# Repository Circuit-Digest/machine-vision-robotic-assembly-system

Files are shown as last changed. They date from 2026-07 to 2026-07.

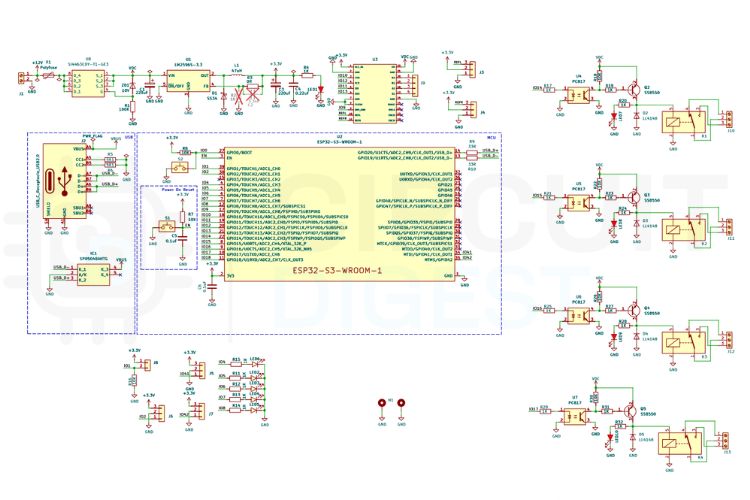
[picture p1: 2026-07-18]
Images/schematics_Controller.jpg

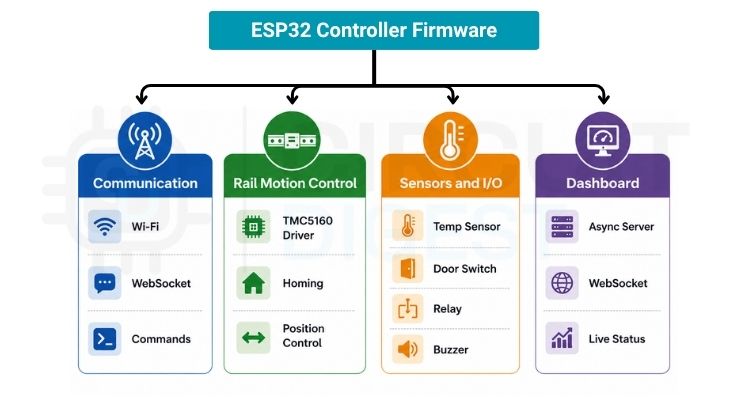
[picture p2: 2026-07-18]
Images/Software-Architecture.jpg

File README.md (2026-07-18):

<div align="center">

# 🤖 Machine Vision-Based Robotic Assembly System Using MechArm 270 and Jetson Nano

**A real-time computer-vision system that drives a 6-DOF robotic arm + linear rail to autonomously assemble two toy cars, verifying every part placement using black-pixel ROI detection on an on-board webcam.**







<br><br>
Robotic Assembly Line Vision Demo

</div>

---

## 📖 Table of Contents

1. [Project Overview](#-project-overview)
2. [Key Features](#-key-features)
3. [System Architecture](#-system-architecture)
4. [Hardware Requirements](#-hardware-requirements)
5. [Software Requirements & Installation](#-software-requirements--installation)
6. [Configuration](#-configuration)
7. [Running the Server](#-running-the-server)
8. [Dashboard Guide](#-dashboard-guide)
9. [Calibration Workflow](#-calibration-workflow)
10. [Vision Pipeline](#-vision-pipeline)
11. [Inspection Stations](#-inspection-stations)
12. [Waypoint System](#-waypoint-system)
13. [Socket.IO Event Reference](#-socketio-event-reference)
14. [Project Structure](#-project-structure)
15. [Troubleshooting](#-troubleshooting)
16. [Contributing](#-contributing)
17. [License](#-license)

---

## 🎯 Project Overview

This system orchestrates a **MechArm 270** 6-DOF robotic arm mounted on a **stepper-driven linear rail** to perform automated, vision-verified pick-and-place assembly of two toy cars.

The arm visits five physical stations. At each inspection station it positions its **wrist-mounted webcam** over a part tray, and a real-time OpenCV pipeline **verifies the correct component is present** using black-pixel ROI analysis before the arm is allowed to pick it up. A missing part immediately halts the sequence, triggers a **physical buzzer alert**, and waits for an operator to place the correct component.

The entire stack — robot control, vision processing, rail control, and web dashboards — runs as a **single Python process on port 5000**, eliminating all inter-service network latency.

---

## ✨ Key Features

| Feature | Description |
|---|---|
| 🎥 **Live MJPEG Stream** | Real-time webcam feed with annotated ROI overlays served to the browser |
| 🔍 **Black-Pixel ROI Detection** | Station-aware part detection using calibrated bounding boxes and HSV black masking |
| 🤖 **Wi-Fi Arm Control** | Non-blocking TCP socket control of MechArm 270 via `pymycobot` |
| 🚂 **ESP32 Rail Control** | HTTP-driven stepper linear rail with 5 presets (P1–P5) |
| 🚦 **Physical Indicators** | Green/Red LED + buzzer relay control for workshop-audible alerts |
| ✅ **Assembly Checklist** | Live progress bar and per-part checklist updating on every verification |
| 🖥️ **Three Dashboards** | Home display, Operator dashboard, Waypoint editor — all browser-based |
| 🛡️ **Sim Mode Fallback** | Full simulation when no hardware is connected — no code changes needed |
| 💾 **JSON Persistence** | All waypoints, poses, ROIs, and network config survive server restarts |

---

## 🏗️ System Architecture

```
┌─────────────────────────────────────────────────────────────────┐
│            main.py  (single process, port 5000)       │
│                                                                  │
│  ┌──────────────┐   ┌──────────────┐   ┌─────────────────────┐ │
│  │ RobotManager │   │  RailManager │   │  RailIndicatorMgr   │ │
│  │  Wi-Fi TCP   │   │  HTTP / ESP32│   │  HTTP relay control  │ │
│  └──────┬───────┘   └──────┬───────┘   └──────────┬──────────┘ │
│         │                  │                        │            │
│  ┌──────▼──────────────────▼───────────────────────▼──────────┐ │
│  │                   PlaybackEngine                            │ │
│  │  Sequences arm + rail movements + vision verification       │ │
│  └──────────────────────────┬──────────────────────────────────┘ │
│                             │  shared in-process memory           │
│  ┌──────────────────────────▼──────────────────────────────────┐ │
│  │             vision_thread()  (~30 FPS)                      │ │
│  │   OpenCV: Black-pixel ROI detection per station             │ │
│  └─────────────────────────────────────────────────────────────┘ │
│                                                                  │
│  Flask Routes + Socket.IO  →  Browser Dashboards                │
└─────────────────────────────────────────────────────────────────┘
```

### Data Flow

```
Camera → vision_thread → stable_detected_parts (dict)
                              ↓ (zero-latency in-process read)
                         PlaybackEngine → verifies part → continues sequence
                              ↓
                         Socket.IO → Browser (checklist, log, progress)
```

---

## 🔧 Hardware Requirements

| Component | Specification | Notes |
|---|---|---|
| **Robot Arm** | Elephant Robotics MechArm 270 | Wi-Fi model required |
| **Linear Rail** | Custom stepper rail with ESP32-C6 | 5 presets: P1–P5 |
| **Camera** | USB webcam (640×480 minimum) | Wrist-mounted on arm |
| **Relay Board** | 3-channel relay (12V) | Buzzer + Green/Red LED |
| **Network** | Wi-Fi AP or router | Arm, ESP32, and host PC on same LAN |
| **Host Computer** | Any x86/ARM Linux or Windows PC | Python 3.9+ required |

> [!NOTE]
> The system runs in full **simulation mode** if no hardware is connected. The camera stream is replaced by an animated mock feed, all Socket.IO events fire normally, and you can test the complete UI and checklist flow without any physical hardware.

---

## 💻 Software Requirements & Installation

### 1. Clone the repository

```bash
git clone https://github.com/YOUR_USERNAME/machine-vision-robotic-assembly-system.git
cd machine-vision-robotic-assembly-system
```

### 2. Create a virtual environment (recommended)

```bash
python -m venv venv

# Windows
venv\Scripts\activate

# Linux / macOS
source venv/bin/activate
```

### 3. Install dependencies

```bash
pip install -r requirements.txt
```

### Dependency Overview

| Package | Purpose |
|---|---|
| `flask` | Web server & template rendering |
| `flask-socketio` | Real-time WebSocket transport |
| `requests` | HTTP calls to the ESP32 Rail API |
| `pymycobot` | MechArm 270 Wi-Fi TCP SDK |
| `opencv-python` | Video capture, black-pixel ROI masking, MJPEG stream |
| `numpy` | Array operations for vision pipeline |

---

## ⚙️ Configuration

### Step 1 — Set your network IPs

Edit **`config.py`** and update the two IP constants at the bottom of the file:

```python
ARM_IP         = "192.168.1.100"   # Your MechArm270's Wi-Fi IP address
RAIL_IP        = "192.168.1.101"   # Your ESP32-C6 Rail controller IP
```

> [!TIP]
> You can also set these at runtime **without restarting the server** — open the Operator Dashboard, click the gear icon ⚙️, and enter your IPs. They are saved to `robot_config.json` and `rail_config.json` and take effect immediately.

### Step 2 — Camera index

In `config.py`, set the correct USB camera index:

```python
CAMERA_INDEX = 0    # 0 = default (first USB camera)
                    # 1 = second USB camera, etc.
```

### Step 3 — Vision detection thresholds

Tune these in `config.py` to match your lighting and part colours:

```python
# Black part detection
BLACK_HSV_LOWER = (0,   0,   0)    # HSV lower bound for black
BLACK_HSV_UPPER = (180, 255, 50)   # V < 50 = genuinely dark/black
BLACK_PIXEL_RATIO = 0.10           # 10% of ROI must be black to count as "present"

# Temporal hysteresis (noise suppression)
CONFIRM_FRAMES   = 5    # frames a part must be seen before "stable"
DISAPPEAR_FRAMES = 10   # frames a part must be missing before "lost"
```

### Step 4 — Runtime-persisted configuration files

The following JSON files are auto-generated and updated by the dashboards. They override the `config.py` defaults:

| File | Contents | Editable via |
|---|---|---|
| `robot_config.json` | Arm IP, port, axis calibration offsets | Operator Dashboard ⚙️ |
| `rail_config.json` | Rail ESP32 IP | Operator Dashboard ⚙️ |
| `camera_settings.json` | Brightness, contrast, exposure, gain | Operator Dashboard 🎥 |
| `scan_poses.json` | 6-joint arm angles per inspection station | Waypoint Editor → Scan Poses |
| `roi_boundaries.json` | Per-part pixel bounding boxes (ROI) | Operator Dashboard → ROI Editor |
| `zone_boundaries.json` | Spatial zone definitions per station | Operator Dashboard → Zone Editor |
| `waypoints.json` | Full arm + rail motion sequence | Waypoint Editor |

> [!WARNING]
> The `waypoints.json` included in this repository was recorded on a **specific physical rig**. Joint angles and positions will **not transfer** to a different robot or table layout. You must re-record all waypoints using the Waypoint Editor for your own setup.

---

## 🚀 Running the Server

```bash
python main.py
```

The server starts on `http://0.0.0.0:5000`. Open a browser and navigate to:

| URL | Dashboard |
|---|---|
| `http://localhost:5000/` | 🏠 Home Display Dashboard |
| `http://localhost:5000/camera_view` | 🖥️ Operator Dashboard |
| `http://localhost:5000/editor` | ✏️ Waypoint Editor |

On startup you will see:

```
======================================================================
  Robotic Assembly System (MechArm 270 & Jetson Nano) -> http://localhost:5000
  Robotic Arm + Stepper Linear Rail + Black-pixel ROI Vision Integrated.
======================================================================
```

The robot arm and rail connections are made in the background — if they fail the server continues in simulation mode and retries every 15 seconds.

---

## 🖥️ Dashboard Guide

### 🏠 Home Display Dashboard (`/`)

Clean status overview, suitable for display on a monitor during operation.

```
┌──────────────────────────┬──────────────────────┐
│   Live Camera Stream     │   System Info         │
│   (annotated MJPEG)      │   Robot: MechArm 270  │
│                          │   Detection: Black ROI│
├──────────────────────────┼──────────────────────┤
│   Last Detection         │  Assembly Progress   │
│   Snapshot               │  ████████░░░  75%    │
│                          │                      │
│                          │  ✅ Chassis 1         │
│                          │  ✅ Chassis 2         │
│                          │  ✅ WheelBase 1a      │
│                          │  ⏳ WheelBase 2a      │
│                          │  ...                  │
│                          │                      │
│                          │  Sensor: 24.3°C      │
│                          │  Door: CLOSED        │
│                          │                      │
│                          │  System Log          │
│                          │  ✓ Chassis 1 confirmed│
└──────────────────────────┴──────────────────────┘
```

- **▶ Play Sequence** — starts the full automated assembly run
- **⏹ Stop Arm** — emergency halt

### 🖥️ Operator Dashboard (`/camera_view`)

Full-featured operator view for monitoring and controlling the assembly:

- **Live annotated stream** — ROI boxes (grey → yellow → green), part labels, pixel-ratio readout, station overlay
- **Robot telemetry** — 6 joint angles, XYZ coordinates updated every 200 ms
- **Assembly checklist** — all parts for both cars, updating in real time
- **8-Switch Simulator Panel** — toggle any part as "present" for dry-run testing without physical components
- **Halt/Error Panel** — if the sequence stops on a missing part, this panel shows the reason and a restart button

### ✏️ Waypoint Editor (`/editor`)

Engineering tool for teaching the robot its motion sequence:

1. **Jog controls** — move each of the 6 joints or X/Y/Z coordinates from the browser
2. **Record** — save the current arm pose as a new waypoint (angles, coords, or both)
3. **Edit sequence** — rename, reorder, adjust speed, vacuum action, delay, and rail preset per waypoint
4. **Scan Pose console** — jog the arm to the perfect camera inspection angle, then click **Set P1** (or P2/P4/P5) to save to `scan_poses.json`
5. **Motor calibration** — lock/unlock individual joints, adjust motor power levels
6. **Network settings** — change Arm IP, Rail IP, and speed without restarting the server

---

## 📐 Calibration Workflow

Follow this sequence when setting up on a new physical rig:

```
1. Physical setup
   └─ Mount arm on rail, position part trays at stations P1, P2, P4, P5

2. Network configuration
   └─ Set ARM_IP and RAIL_IP in config.py or via Operator Dashboard ⚙️

3. Camera verification
   └─ Open /camera_view, check live stream
   └─ Adjust CAMERA_INDEX in config.py if wrong camera opens

4. Scan pose recording  (Waypoint Editor → 📸 Inspection Scan Poses)
   └─ Jog arm to view P1 tray → click "Set P1 (Chassis)"
   └─ Repeat for P2, P4, P5

5. ROI calibration  (Operator Dashboard → ROI Editor)
   └─ Move arm to scan pose for each station
   └─ Draw bounding boxes around each part slot on the video frame
   └─ Save → updates roi_boundaries.json

6. Detection threshold tuning  (config.py)
   └─ Adjust BLACK_PIXEL_RATIO until parts detect cleanly
   └─ Use 8-Switch Simulator to verify checklist behaviour

7. Waypoint recording  (Waypoint Editor)
   └─ Record pick positions at each station
   └─ Record place positions at P3 (assembly zone)
   └─ Add vision_check waypoints before each pick
   └─ Test with "Skip Vision" mode first, then enable vision checks

8. Full test run
   └─ Place parts at all stations
   └─ Click ▶ Play Sequence on Home Dashboard
   └─ Verify checklist completes 100%
```

---

## 👁️ Vision Pipeline

The vision system runs in a **dedicated background thread** at ~30 FPS using OpenCV.

### Black-Pixel ROI Detection

The only detection method used is black-pixel ratio analysis within calibrated Region of Interest (ROI) bounding boxes:

```
Frame (BGR)
  │
  ├─ GaussianBlur (5×5) → HSV conversion
  │
  └─ For each active part at current station:
        Crop frame to ROI bounding box  (from roi_boundaries.json)
        Apply black HSV mask: H[0-180] S[0-255] V[0-50]
        ratio = countNonZero(mask) / roi_area
        present = ratio - ambient_baseline ≥ BLACK_PIXEL_RATIO (10%)
```

An **adaptive ambient baseline** is captured on the first frame after the arm settles at its scan pose. This compensates automatically for dim environments or dark surfaces in the background.

### How Detection Works Per Station

1. Rail moves arm to station (e.g. P1)
2. Arm commands itself to pre-saved scan pose for that station (`scan_poses.json`)
3. Vision thread activates and begins checking only the parts registered to that station (`STATION_PARTS` in `config.py`)
4. For each active part slot, it crops the frame to the ROI (`roi_boundaries.json`) and measures the black-pixel ratio
5. Parts meeting the threshold are accumulated over frames; confirmed after `CONFIRM_FRAMES` consecutive detections

### Hysteresis Filtering

Raw frame results are not immediately acted upon — a two-stage filter prevents false positives from motion blur, shadows, or lighting glitches:

```
MISSING ──[seen for 5 consecutive frames]──→ STABLE (detected)
STABLE  ──[missing for 10 consecutive frames]──→ MISSING
```

### Stream Annotation

During an active vision check, the live stream shows:

- **Grey boxes** — ROI is active, part not detected
- **Yellow boxes** — part seen but not yet stable (accumulating frames)
- **Green boxes** — part confirmed stable (checkmark ✓ + ratio %)
- **Station panel** — current station label + list of active part slots

---

## 🏭 Inspection Stations

| Station | Preset | Detection Method | Parts Verified |
|---|---|---|---|
| **P1** | `P1 (Chassis)` | Black-pixel ROI | Chassis 1, Chassis 2 |
| **P2** | `P2 (Wheelbase)` | Black-pixel ROI | WheelBase 1a, 2a, 1b, 2b |
| **P3** | `P3 (Assemble)` | *(none — assembly zone)* | — |
| **P4** | `P4 (Wheels)` | Black-pixel ROI (8 slots) | Wheel Slots 1–8 |
| **P5** | `P5 (Body)` | Black-pixel ROI | Body 1, Body 2 |

---

## 📋 Waypoint System

### Waypoint Record Format

```json
{
  "name": "Pick Chassis 1",
  "type": "angles",
  "data": [15.2, -45.1, 90.0, 0.0, 45.0, 0.0],
  "speed": 40,
  "vacuum": "on",
  "vacuum_delay_ms": 300,
  "delay_ms": 200,
  "rail_preset": "P1"
}
```

| Field | Values | Description |
|---|---|---|
| `type` | `angles`, `coords`, `both`, `vision_check` | Movement type |
| `data` | `[j1, j2, j3, j4, j5, j6]` or `[x, y, z, rx, ry, rz]` | Target position |
| `vacuum` | `"on"`, `"off"`, `"none"` | Vacuum pump action after movement |
| `rail_preset` | `"P1"`–`"P5"`, `"NONE"` | Rail position to move to after arm arrives |
| `speed` | `1`–`100` | Arm movement speed percentage |

### `vision_check` Waypoint

A special waypoint type that **does not move the arm or rail**. It triggers a vision verification cycle:

```json
{
  "name": "Verify Chassis 1",
  "type": "vision_check",
  "rail_preset": "P1",
  "check_part": "Chassis 1"
}
```

When the PlaybackEngine reaches this waypoint it:
1. Commands the arm to the pre-saved scan pose for that station
2. Waits 1.5 s for mechanical settling
3. Activates vision detection for the named part
4. Waits until the part is stably detected (or halts on timeout/stop)
5. Emits `part_verified` to update the UI checklist

---

## 📡 Socket.IO Event Reference

### Server → Client

| Event | Key Payload Fields | Description |
|---|---|---|
| `robot_status` | `angles[]`, `coords[]`, `rail{}`, `vision_detected[]` | Full telemetry broadcast (every 200 ms) |
| `status` | `state`, `step`, `total`, `message` | Playback state machine update |
| `playback_progress` | `index`, `total`, `name`, `state` | Per-waypoint progress update |
| `part_verified` | `part`, `rail`, `snapshot_ts` | Part confirmed — update checklist |
| `vision_log` | `level`, `message` | Colour-coded log line for consoles |
| `detection_started` | `part`, `station` | Vision scan is active |
| `detection_stopped` | `part`, `station`, `found` | Vision scan ended |
| `snapshot_updated` | *(none)* | Last-detection image on disk has changed |
| `error` | `part`, `position`, `message` | Emergency stop / verification fault |
| `command_complete` | `action`, `cmd_id` | Arm command acknowledged by hardware |

### Client → Server

| Event | Payload | Description |
|---|---|---|
| `play_sequence` | `start_index`, `speed`, `skip_vision` | Start playback |
| `stop_sequence` | *(none)* | Emergency stop |
| `toggle_mock` | `part`, `value` | Toggle hardware simulator switch |
| `jog_joint` | `joint`, `delta`, `speed` | Move one joint by delta degrees |
| `jog_coord` | `axis`, `delta`, `speed` | Move in Cartesian space |
| `record_waypoint` | `type`, `name`, `vacuum`, `rail_preset`, `speed` | Save current pose |
| `set_scan_pose` | `station` | Save current arm angles as scan pose |
| `update_ip` | `arm_ip`, `rail_ip` | Change network config without restart |

---

## 📁 Project Structure

```
machine-vision-robotic-assembly-system/
│
├── main.py                    # Main Flask + SocketIO application (2,700+ lines)
├── config.py                  # Shared constants: IPs, HSV thresholds, station maps
├── requirements.txt           # Python dependencies
├── .gitignore                 # Excludes __pycache__, logs, runtime snapshots
├── LICENSE                    # MIT License
│
├── templates/
│   ├── home.html              # 🏠 Home display (live feed + status checklist)
│   ├── operator_view.html     # 🖥️  Operator Dashboard (full telemetry + controls)
│   └── waypoint_editor.html   # ✏️  Waypoint Editor & Scan Pose console
│
├── static/
│   └── socket.io.min.js       # Socket.IO client (served locally, no CDN dependency)
│
├── hardware/                  # 🔌 PCB & Schematic Design Files
│   ├── schematic.pdf          # PCB schematic diagram (PDF)
│   ├── gerbers.zip            # Manufacturing-ready Gerber files
│   ├── controller.kicad_sch   # KiCad Schematic design
│   ├── controller.kicad_pcb   # KiCad PCB board layout
│   ├── controller.kicad_pro   # KiCad Project file
│   └── controller.kicad_prl   # KiCad Project local settings
│
├── Images/                    # 🖼️ Documentation Media Files
│   ├── vision_demo.gif        # Animated GIF showing the real-time vision tracking
│   ├── pcb_render.png         # 3D render of the custom PCB board
│   ├── pcb_layout.png         # 2D layout layout of the PCB routing
│   ├── control_panel.jpg      # Physical photo/render of the control panel
│   └── cad_render.png         # 3D CAD rendering of the full assembly layout
│
├── waypoints.json             # Recorded motion sequence (re-record for your rig)
├── scan_poses.json            # Camera inspection arm poses per station
├── roi_boundaries.json        # Calibrated per-part ROI bounding boxes (pixels)
├── zone_boundaries.json       # Spatial zone definitions per station
├── camera_settings.json       # USB camera brightness/contrast/exposure settings
├── robot_config.json          # Runtime arm IP config (overrides config.py)
└── rail_config.json           # Runtime rail IP config (overrides config.py)
```

---

## 🔧 Troubleshooting

### Robot arm won't connect

- Confirm the MechArm 270 is powered on and joined to your Wi-Fi network
- Check `ARM_IP` in `config.py` or `robot_config.json` matches the arm's actual IP
- The arm's IP is shown on the robot's display or in your router's DHCP table
- The server retries the connection every 15 seconds — check the console for `Wi-Fi connect failed` messages

### Rail won't move

- Confirm the ESP32-C6 board is powered and on the same LAN
- Check `RAIL_IP` in `config.py` or `rail_config.json`
- Open `http://YOUR_RAIL_IP/status` in a browser — you should get a JSON response

### Camera not opening / black screen

- Try changing `CAMERA_INDEX` in `config.py` (0, 1, 2 …)
- On Linux, if using V4L2: ensure `CAMERA_BACKEND = "CAP_V4L2"` in `config.py`
- Check that no other application has the camera locked

### Parts not being detected

- Verify the arm reaches the correct scan pose (check `scan_poses.json`)
- Use the **ROI Editor** in the Operator Dashboard to confirm the bounding boxes are positioned over the part slots
- Lower `BLACK_PIXEL_RATIO` in `config.py` if detection is too strict
- Check ambient lighting — very bright or uneven light can wash out the black pixel mask

### Detection works in sim but not on hardware

- Verify `roi_boundaries.json` is calibrated for your actual camera view angle (sim uses default zones)
- Re-run the scan pose recording for each station in the Waypoint Editor

---

## 🤝 Contributing

Contributions, bug reports, and feature suggestions are welcome!

1. **Fork** the repository
2. Create a feature branch: `git checkout -b feature/your-feature-name`
3. Commit your changes: `git commit -m "feat: add your feature description"`
4. Push to your fork: `git push origin feature/your-feature-name`
5. Open a **Pull Request** against the `main` branch

### Code Style

- Python: follow [PEP 8](https://pep8.org/)
- Docstrings: include for all new public functions and classes
- Existing `# ─────` section dividers should be preserved for consistency

---

## 📄 License

This project is licensed under the **MIT License** — see the [LICENSE](LICENSE) file for details.

---

<div align="center">

Built with ❤️ using **Flask · OpenCV · pymycobot · Socket.IO**

</div>

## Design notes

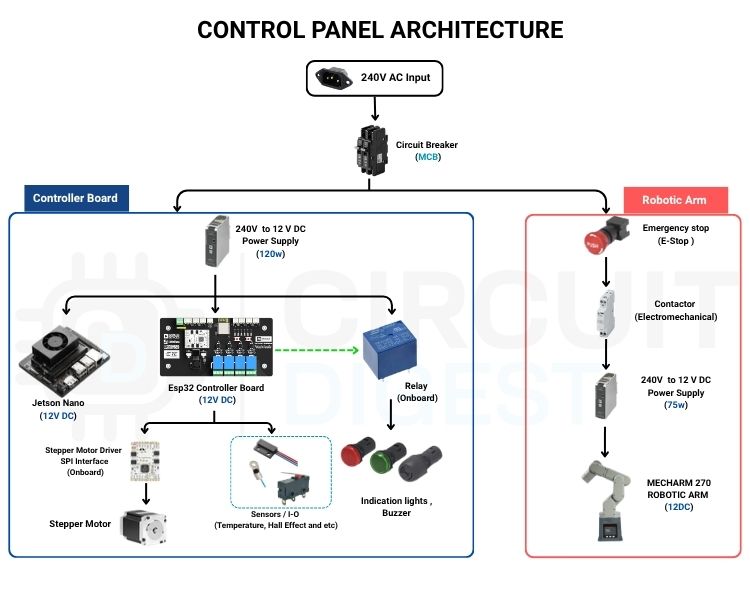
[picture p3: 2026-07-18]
Images/Control-Panel-Architecture.jpg

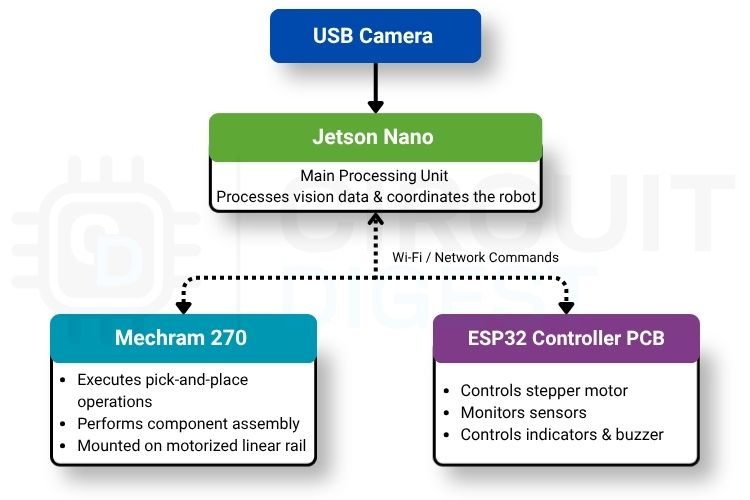
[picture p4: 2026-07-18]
Images/system_overview.jpg

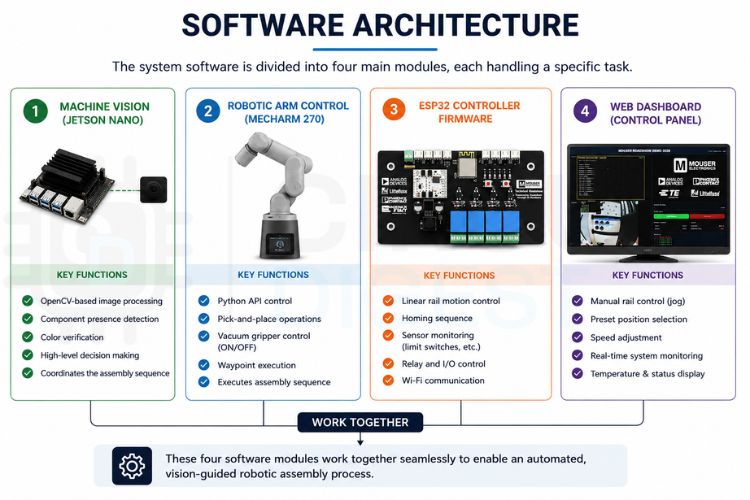
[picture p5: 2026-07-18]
Images/software_architecture.jpg

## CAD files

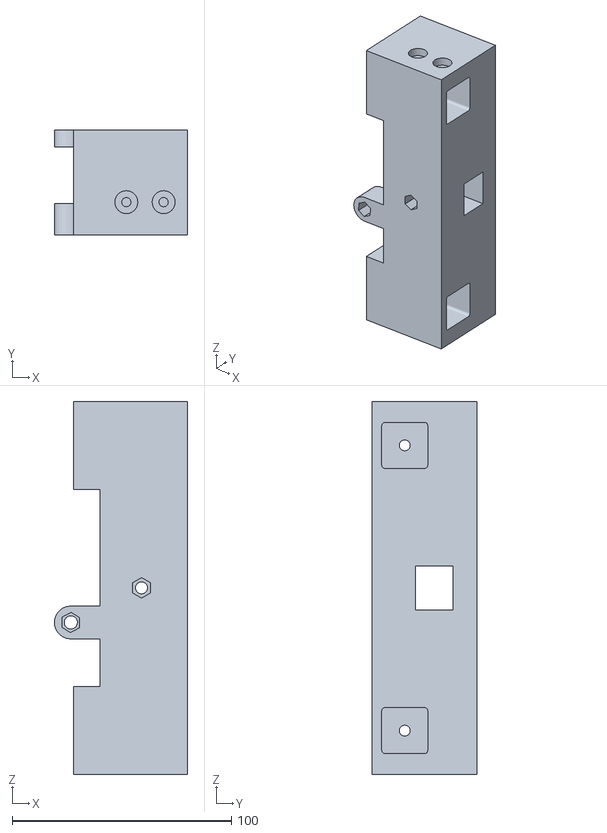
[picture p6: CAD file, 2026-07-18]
3D-Print_files/Idler_Pulley_Base.stl
60.8 x 48.0 x 170.0

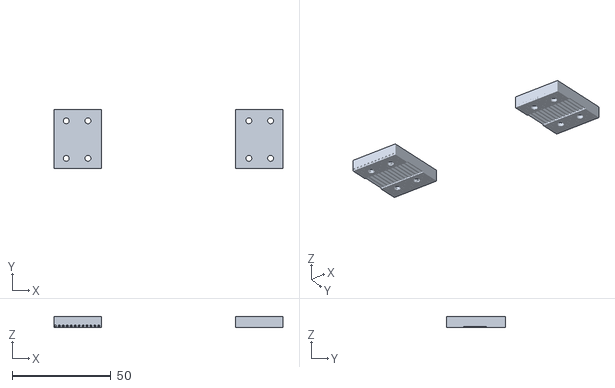
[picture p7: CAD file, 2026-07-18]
3D-Print_files/Belt Retainer.stl
116.0 x 30.0 x 5.51

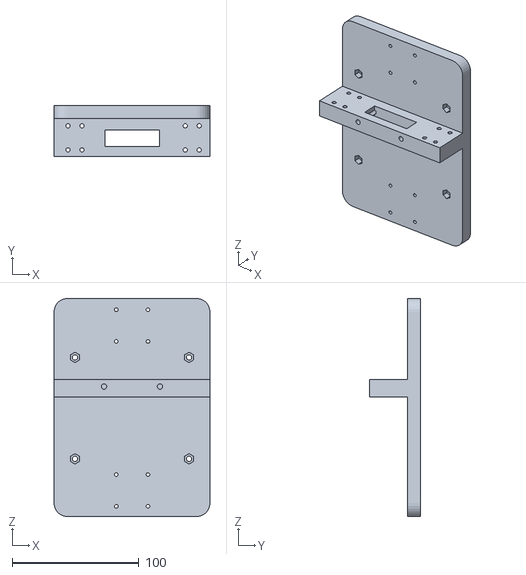
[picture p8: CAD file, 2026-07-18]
3D-Print_files/RoboticArm_Base.stl
122.9 x 40.2 x 171.9

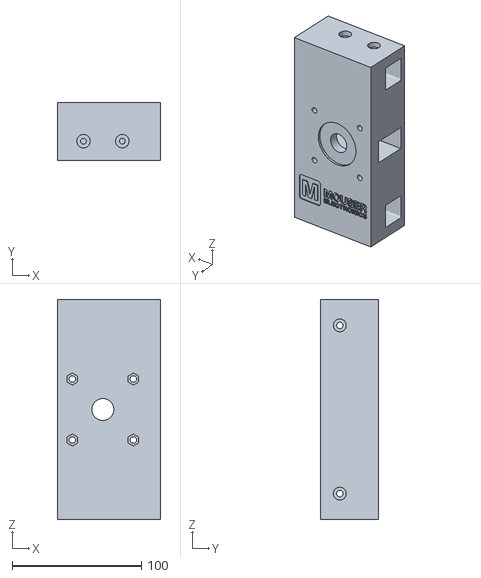
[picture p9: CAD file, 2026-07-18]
3D-Print_files/Stepper_Motor_Base.stl
79.5 x 45.0 x 170.0

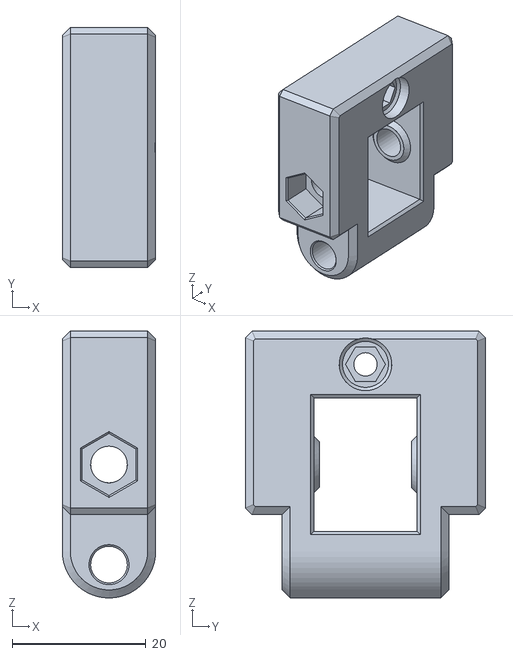
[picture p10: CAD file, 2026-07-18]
3D-Print_files/Belt Tensioner.stl
14.0 x 36.0 x 40.0

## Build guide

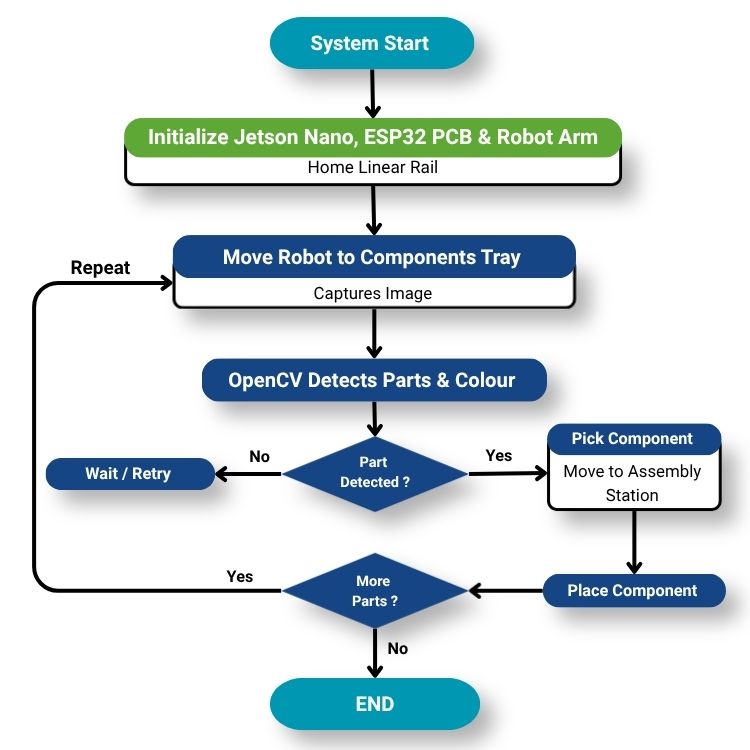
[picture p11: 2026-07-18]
Images/Assembly-Workflow.jpg

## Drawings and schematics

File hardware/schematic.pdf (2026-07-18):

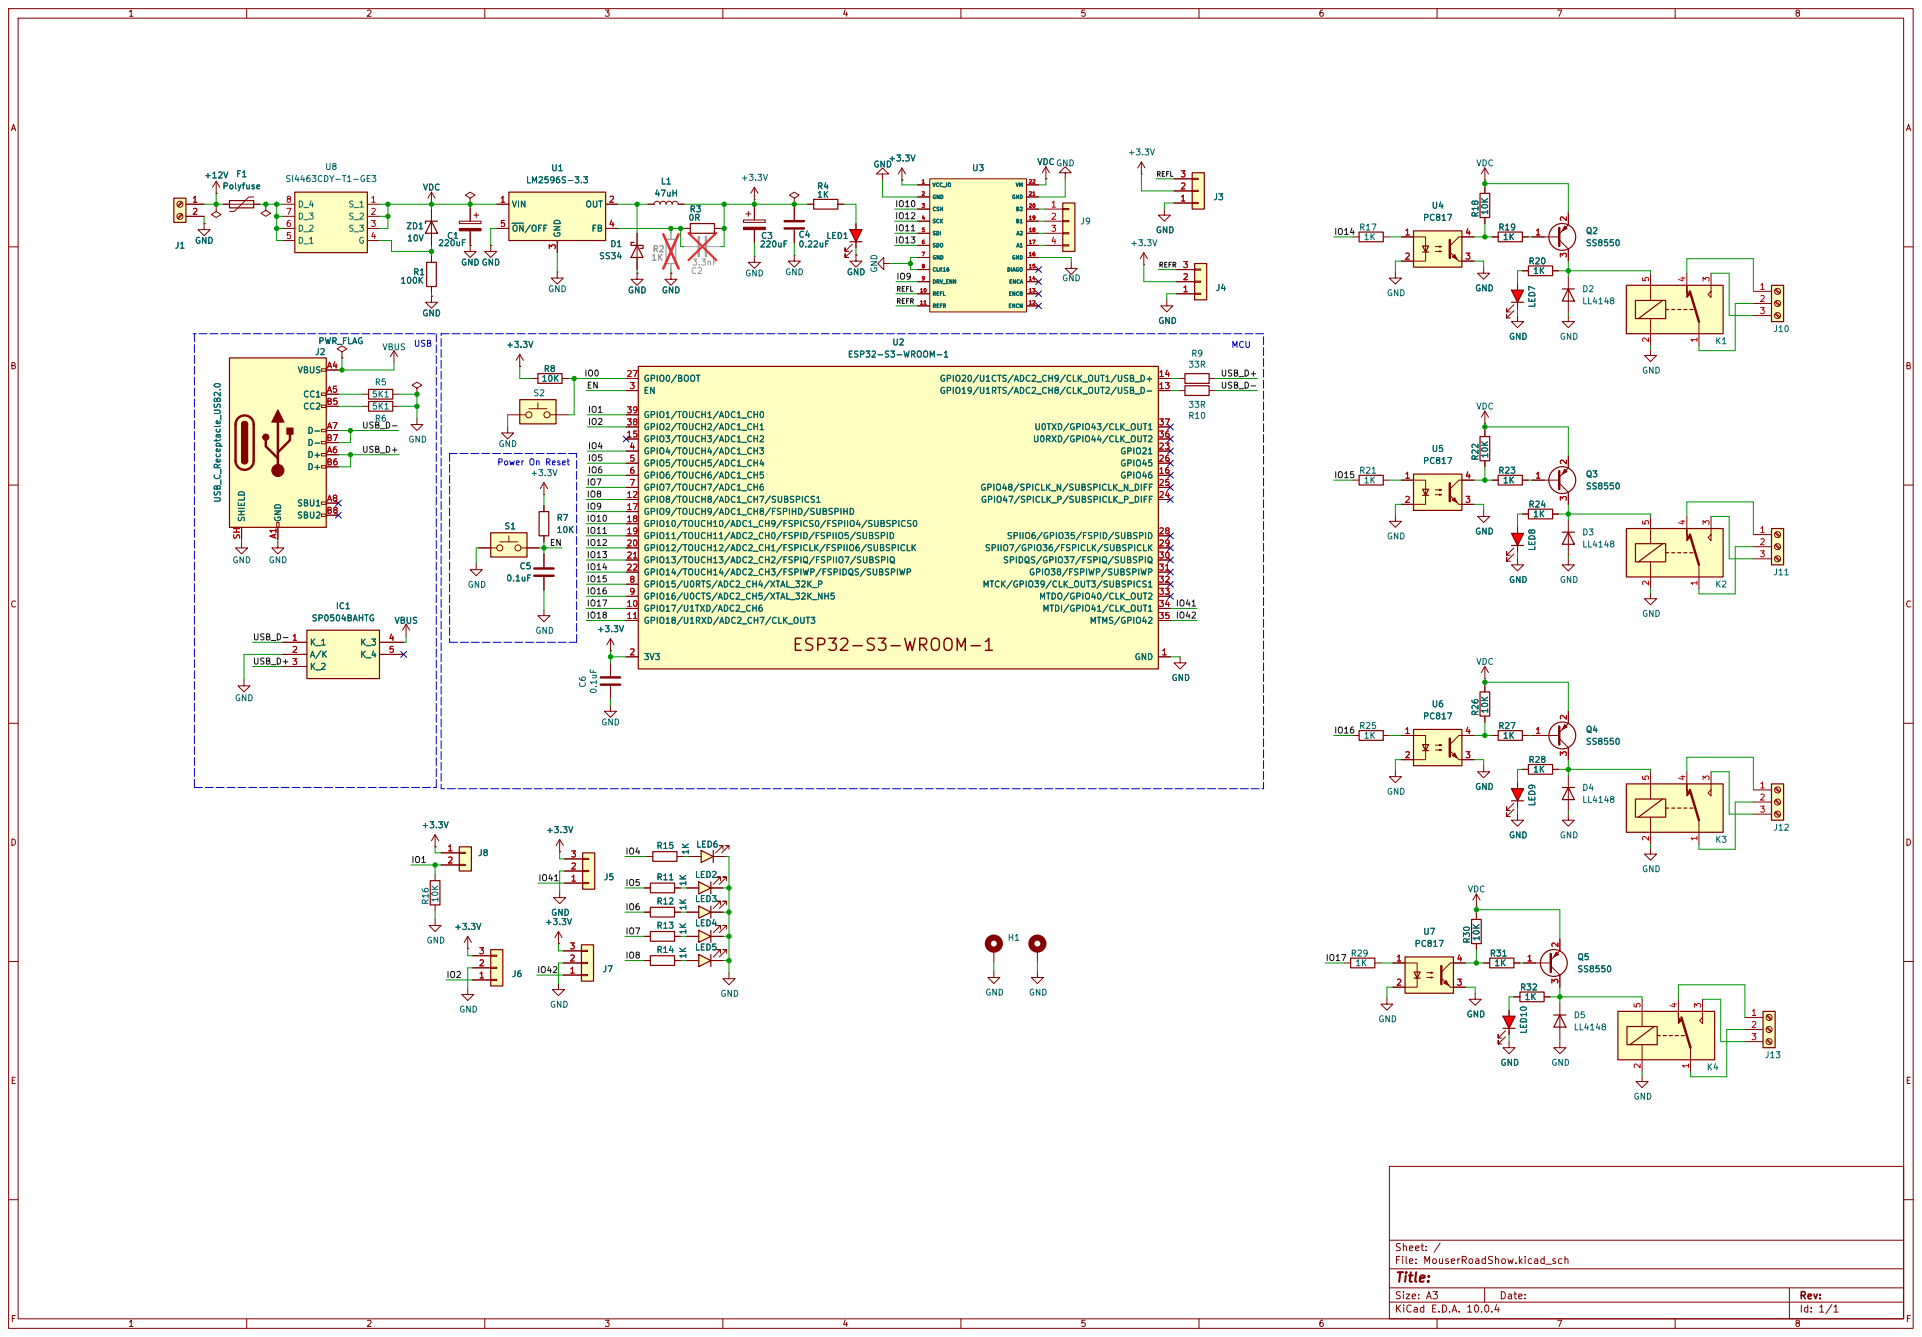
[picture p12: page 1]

Size: A3 | Rev:

F Date: KiCad E.D.A. 10.0.4

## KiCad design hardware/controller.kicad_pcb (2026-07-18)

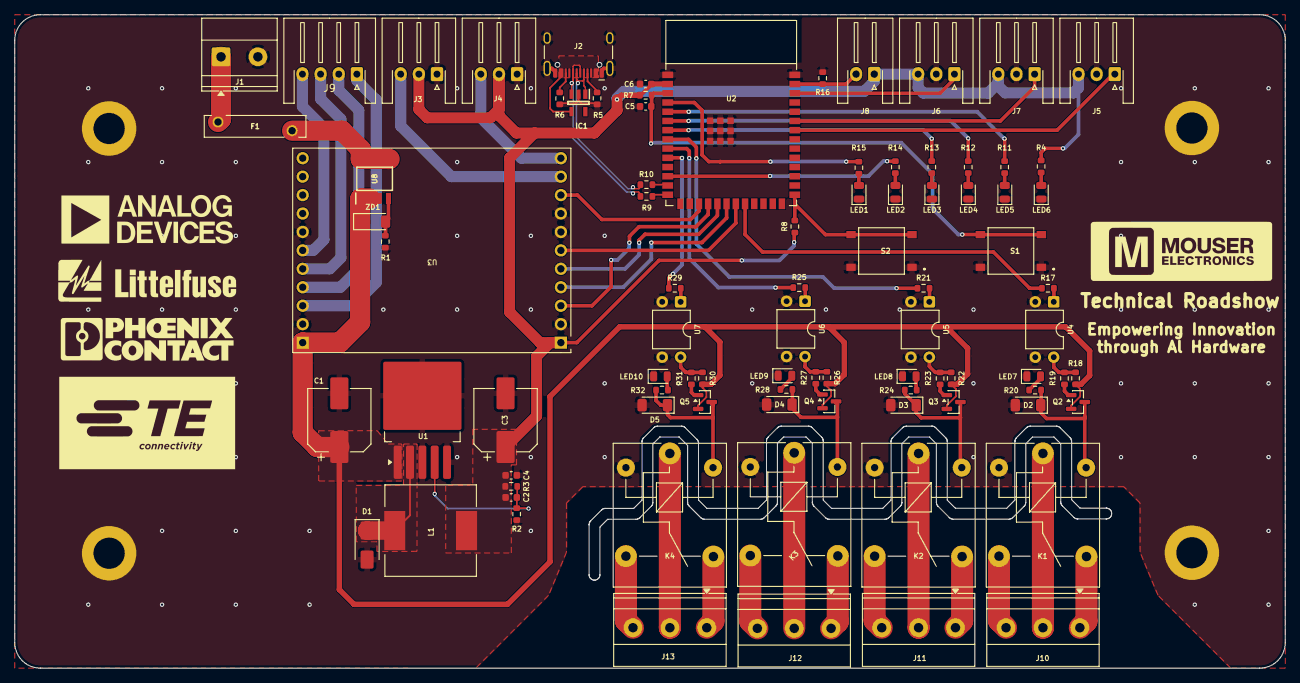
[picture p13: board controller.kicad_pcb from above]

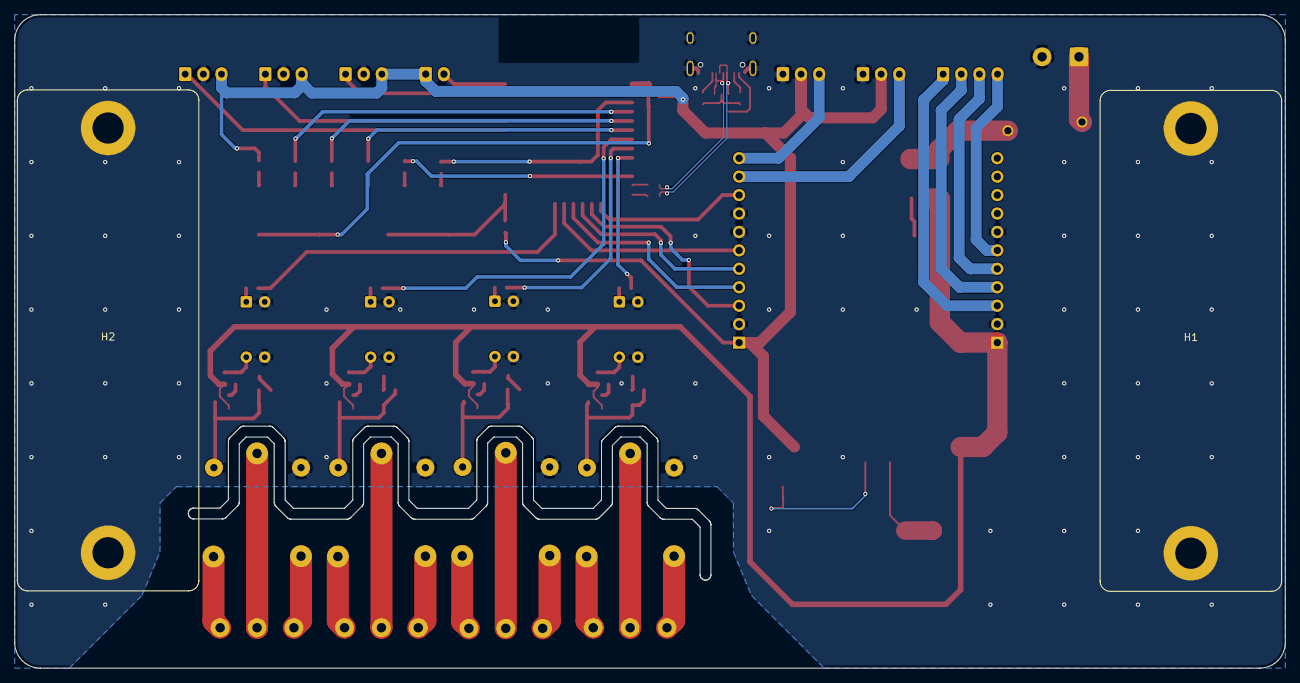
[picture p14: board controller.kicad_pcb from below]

Board: 2 copper layers, 175.0 x 90.0 mm, 90 parts (2 on the bottom side), 79 nets.

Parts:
C1, C3: 220uF; CP_Elec_8x10.5
C2: 3.3nF; C_0603_1608Metric
C4: 0.22uF; C_0603_1608Metric
C5, C6: 0.1uF; C_0603_1608Metric
D1: SS34; D_SMA
D2, D3, D4, D5: LL4148; D_MiniMELF
F1: Polyfuse; 30R500UF
H1, H2: MountingHole_Pad; DinRailMount
IC1: SP0504BAHTG; SOT95P280X145-5N
J1: Screw_Terminal_01x02; TerminalBlock_Phoenix_MKDS-1,5-2-5.08_1x02_P5.08mm_Horizont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
J2: USB_C_Receptacle_USB2.0; USB_C_Receptacle_HCTL_HC-TYPE-C-16P-01A
J3, J4, J5, J6, J7: Conn_01x03; JST_XH_S3B-XH-A-1_1x03_P2.50mm_Horizontal
J8: Conn_01x02; JST_XH_S2B-XH-A-1_1x02_P2.50mm_Horizontal
J9: Conn_01x04; JST_XH_S4B-XH-A-1_1x04_P2.50mm_Horizontal
J10, J11, J12, J13: Screw_Terminal_01x03; TerminalBlock_Phoenix_MKDS-1,5-3-5.08_1x03_P5.08mm_Horizont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
K1, K2, K3, K4: SANYOU_SRD_Form_C; Relay_SPDT_SANYOU_SRD_Series_Form_C
L1: 47uH; L_12x12mm_H8mm
LED1, LED2, LED3, LED4, LED5: LED Red; LED_0805_2012Metric
LED6, LED7, LED8, LED9, LED10: 3mm Red LED with 13mm Spacer; LED_0805_2012Metric
Q2, Q3, Q4, Q5: SS8550; SOT-23
R1: 100K; R_0603_1608Metric
R2, R4, R11, R12, R13, R14, R15, R17, R19, R20, R21, R23, R24, R25, R27, R28, R29, R31, R32: 1K; R_0603_1608Metric
R3: 0R; R_0603_1608Metric
R5, R6: 5K1; R_0603_1608Metric
R7, R8, R16, R18, R22, R26, R30: 10K; R_0603_1608Metric
R9, R10: 33R; R_0603_1608Metric
S1, S2: PTS641_SM25_SMTR2_LFS; PTS641SM25SMTR2LFS
U1: LM2596S-3.3; TO-263-5_TabPin3
U2: ESP32-S3-WROOM-1
U3: TMC5160_BOB
U4, U5, U6, U7: PC817; DIP-4_W7.62mm
U8: SI4463CDY-T1-GE3; SOIC127P600X175-8N
ZD1: 10V; D_MiniMELF

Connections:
+3.3V: C2.2, C3.1, C4.1, C6.1, J3.2, J4.2, J5.3, J6.3, J7.3, J8.1, L1.2, R3.1, R4.1, R7.1, R8.1, U2.2 (3V3), U3.1 (VCC_IO)
+12V: F1.1, J1.1
/EN: C5.1, R7.2, S1.3 (NO_1), S1.4 (NO_2), U2.3 (EN)
/IO0: R8.2, S2.3 (NO_1), S2.4 (NO_2), U2.27 (GPIO0/BOOT)
/IO1: J8.2, R16.2, U2.39 (GPIO1/TOUCH1/ADC1_CH0)
/IO2: J6.1, U2.38 (GPIO2/TOUCH2/ADC1_CH1)
/IO4: R15.1, U2.4 (GPIO4/TOUCH4/ADC1_CH3)
/IO5: R11.1, U2.5 (GPIO5/TOUCH5/ADC1_CH4)
/IO6: R12.1, U2.6 (GPIO6/TOUCH6/ADC1_CH5)
/IO7: R13.1, U2.7 (GPIO7/TOUCH7/ADC1_CH6)
/IO8: R14.1, U2.12 (GPIO8/TOUCH8/ADC1_CH7/SUBSPICS1)
/IO9: U2.17 (GPIO9/TOUCH9/ADC1_CH8/FSPIHD/SUBSPIHD), U3.9 (DRV_ENN)
/IO10: U2.18 (GPIO10/TOUCH10/ADC1_CH9/FSPICS0/FSPIIO4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), U3.3 (CSN)
/IO11: U2.19 (GPIO11/TOUCH11/ADC2_CH0/FSPID/FSPIIO5/S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), U3.5 (SDI)
/IO12: U2.20 (GPIO12/TOUCH12/ADC2_CH1/FSPICLK/FSPIIO6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), U3.4 (SCK)
/IO13: U2.21 (GPIO13/TOUCH13/ADC2_CH2/FSPIQ/FSPIIO7/S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), U3.6 (SDO)
/IO14: R17.1, U2.22 (GPIO14/TOUCH14/ADC2_CH3/FSPIWP/FSPIDQS/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)
/IO15: R21.1, U2.8 (GPIO15/U0RTS/ADC2_CH4/XTAL_32K_P)
/IO16: R25.1, U2.9 (GPIO16/U0CTS/ADC2_CH5/XTAL_32K_NH5)
/IO17: R29.1, U2.10 (GPIO17/U1TXD/ADC2_CH6)
/IO41: J5.1, U2.34 (MTDI/GPIO41/CLK_OUT1)
/IO42: J7.1, U2.35 (MTMS/GPIO42)
/REFL: J3.3, U3.10 (REFL)
/REFR: J4.3, U3.11 (REFR)
/USB_D+: IC1.3 (K_2), J2.A6 (D+), J2.B6 (D+), R9.1
/USB_D-: IC1.1 (K_1), J2.A7 (D-), J2.B7 (D-), R10.1
GND: C1.2, C3.2, C4.2, C5.2, C6.2, D1.2 (A), D2.2 (A), D3.2 (A), D4.2 (A), D5.2 (A), H1.1 (1_1), H2.1 (1_1), IC1.2 (A/K), J1.2, J2.A1 (GND), J2.A12 (GND), J2.B1 (GND), J2.B12 (GND), J2.SH (SHIELD), J3.1, J4.1, J5.2, J6.2, J7.2, K1.2, K2.2, K3.2, K4.2, LED1.1 (K), LED2.1 (K), LED3.1 (K), LED4.1 (K), LED5.1 (K), LED6.1 (K), LED7.1 (K), LED8.1 (K), LED9.1 (K), LED10.1 (K), R1.2, R2.2, R5.1, R6.1, R16.1, S1.1 (COM_1), S1.2 (COM_2), S2.1 (COM_1), S2.2 (COM_2), U1.3 (GND), U1.5 (~ON/OFF), U2.1 (GND), U2.40 (GND), U2.41 (GND), U3.2 (GND), U3.7 (GND), U3.8 (CLK16), U3.16 (GND), U3.21 (GND), U4.2, U4.3, U5.2, U5.3, U6.2, U6.3, U7.2, U7.3
unnamed: D1.1 (K), L1.1, U1.2 (OUT)
unnamed: D2.1 (K), K1.5, Q2.3 (C), R20.2
unnamed: D3.1 (K), K2.5, Q3.3 (C), R24.2
unnamed: D4.1 (K), K3.5, Q4.3 (C), R28.2
unnamed: D5.1 (K), K4.5, Q5.3 (C), R32.2
unnamed: J2.A5 (CC1), R5.2
unnamed: J2.B5 (CC2), R6.2
unnamed: J9.1, U3.20 (B2)
unnamed: J9.2, U3.19 (B1)
unnamed: J9.3, U3.18 (A2)
unnamed: J9.4, U3.17 (A1)
unnamed: J10.1, K1.4
unnamed: J10.2, K1.1
unnamed: J10.3, K1.3
unnamed: J11.1, K2.4
unnamed: J11.2, K2.1
unnamed: J11.3, K2.3
unnamed: J12.1, K3.4
unnamed: J12.2, K3.1
unnamed: J12.3, K3.3
unnamed: J13.1, K4.4
unnamed: J13.2, K4.1
unnamed: J13.3, K4.3
unnamed: LED6.2 (A), R4.2
unnamed: LED5.2 (A), R11.2
unnamed: LED4.2 (A), R12.2
unnamed: LED3.2 (A), R13.2
unnamed: LED2.2 (A), R14.2
unnamed: LED1.2 (A), R15.2
unnamed: LED7.2 (A), R20.1
unnamed: LED8.2 (A), R24.1
unnamed: LED9.2 (A), R28.1
unnamed: LED10.2 (A), R32.1
unnamed: Q2.1 (B), R19.2
unnamed: Q3.1 (B), R23.2
unnamed: Q4.1 (B), R27.2
unnamed: Q5.1 (B), R31.2
unnamed: R17.2, U4.1
unnamed: R18.1, R19.1, U4.4
unnamed: R21.2, U5.1
unnamed: R22.1, R23.1, U5.4
unnamed: R25.2, U6.1
unnamed: R26.1, R27.1, U6.4
unnamed: R29.2, U7.1
unnamed: R30.1, R31.1, U7.4
unnamed: C2.1, R2.1, R3.2, U1.4 (FB)
unnamed: R10.2, U2.13 (GPIO19/U1RTS/ADC2_CH8/CLK_OUT2/USB_D-)
unnamed: R9.2, U2.14 (GPIO20/U1CTS/ADC2_CH9/CLK_OUT1/USB_D+)
unnamed: F1.2, U8.5 (D_1), U8.6 (D_2), U8.7 (D_3), U8.8 (D_4)
unnamed: R1.1, U8.4 (G), ZD1.2 (A)
VBUS: IC1.4 (K_3), J2.A4 (VBUS), J2.A9 (VBUS), J2.B4 (VBUS), J2.B9 (VBUS)
VDC: C1.1, Q2.2 (E), Q3.2 (E), Q4.2 (E), Q5.2 (E), R18.2, R22.2, R26.2, R30.2, U1.1 (VIN), U3.22 (VM), U8.1 (S_1), U8.2 (S_2), U8.3 (S_3), ZD1.1 (K)

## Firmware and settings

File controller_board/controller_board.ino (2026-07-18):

/**
 * ============================================================================
 * MOUSER ROADSHOW - LINEAR RAIL CONTROLLER FIRMWARE
 * ============================================================================
 * Hardware Platform: ESP32-S3 + TMC5160 Stepper Driver (SPI Mode)
 *
 * OVERVIEW:
 * This firmware coordinates a linear rail system equipped with an ESP32-S3 and
 * a TMC5160 driver running at 256 microsteps. It exposes an HTTP REST API and
 * a web dashboard over Wi-Fi for manual control and integration with Python.
 *
 * FIXES APPLIED vs original:
 * 1. CS pin pulled HIGH before SPI.begin() to prevent garbage initialization.
 * 2. VMAX/AMAX/DMAX scaled correctly for 256 microsteps.
 * 3. VSTOP raised to a safe value (was 10, now 200).
 * 4. VMAX correctly restored after homing (was wrong value).
 * 5. Homing guards against mid-move re-trigger.
 * 6. moveToIndex() guards against calling before homing is completed.
 * 7. Homing uses large negative XTARGET (positioning mode) — direction-agnostic.
 * 8. Live speed control via web dashboard slider + /speed?v=N endpoint.
 * 9. Relay-controlled 12V indicators:
 *    - GPIO 14 — Red LED relay (constant ON when object NOT detected).
 *    - GPIO 17 — Buzzer relay (beeps every 2 s when object NOT detected).
 *    - GPIO 15 — Green LED relay (ON when object is detected / system ready).
 * 10. Added /bypass_homing endpoint and dashboard button for bench/dry testing.
 *
 * CORE FUNCTIONALITIES:
 * 1. Stepper Motor Control (TMC5160):
 *    - Uses TMCStepper SPI configuration.
 *    - Non-blocking homing sequence triggered automatically on boot or via HTTP.
 *    - Absolute positioning mode for navigating between pre-configured travel
 *      presets (P1 to P5) once homed.
 *    - Guard checks to prevent moves before homing or over-travel hazards.
 *
 * 2. HTTP Server & REST API:
 *    - Exposes endpoints to check status (/status), trigger homing (/home),
 *      bypass homing for dry tests (/bypass_homing), halt movement (/stop),
 *      and direct preset commands (/p1 through /p5).
 *    - Exposes an indicator override endpoint (/indicator) and speed adjustment
 *      endpoint (/speed).
 *
 * 3. 12V Indicators (Relay Controlled):
 *    - Red LED & Buzzer: Active-HIGH relays signaling missing parts, door-open
 *      alerts, or homing failures.
 *    - Green LED: Active-HIGH relay signaling target preset reached / system ready.
 *    - Supports automatic internal logic and external overrides from Python.
 *
 * 4. Auxiliary Sensors:
 *    - Temperature Sensor: NTC thermistor read via oversampled analog ADC pin.
 *    - Door Sensor: TMR magnetic sensor monitoring door closure status.
 * ============================================================================
 */

#include <Arduino.h>
#include <SPI.h>
#include <TMCStepper.h>
#include <WiFi.h>
#include <WebServer.h>

// ─── WiFi Credentials ──────────────────────────────────────────────────────
const char *WIFI_SSID = "MyCobotWiFi2.4G";
const char *WIFI_PASS = "mycobot123";

// ─── PCB Pin Map (Mouser RoadShow Board) ───────────────────────────────────
#define PIN_TMC_CS   10
#define PIN_TMC_SCK  12
#define PIN_TMC_MOSI 11
#define PIN_TMC_MISO 13
#define PIN_TMC_EN   9
#define PIN_BUTTON_S2 41  // Home switch (active LOW)

// ─── Relay / Indicator Pins (12V via relay, active HIGH) ───────────────────
#define PIN_RELAY_RED    14  // Red  LED  relay
#define PIN_RELAY_BUZZER 17  // Buzzer    relay
#define PIN_RELAY_GREEN  15  // Green LED relay

// ─── Sensor Pins ───────────────────────────────────────────────────────────
#define PIN_NTC_TEMP    1   // ADC — NTC thermistor (10kΩ B=3950, NTC to 3.3V, 10k pull-down to GND)
#define PIN_DOOR_SENSOR 2   // Digital — TMR 54140 (LOW = magnet present = door closed)

// ─── NTC Config ────────────────────────────────────────────────────────────
#define NTC_BETA        3950.0f   // Beta coefficient
#define NTC_NOMINAL    10000.0f   // Resistance at 25°C (10kΩ)
#define NTC_PULLUP     10000.0f   // Pull-up resistor value (10kΩ to 3.3V)
#define TEMP_NOMINAL    298.15f   // 25°C in Kelvin
#define NTC_SAMPLES         16   // Oversample count — averages out ADC noise

// ─── Indicator Timing ──────────────────────────────────────────────────────
#define BUZZER_INTERVAL_MS 2000UL  // Buzzer beep period (ms)
#define BUZZER_BEEP_MS      150UL  // Relay ON duration per beep (ms)

// ─── Door Alert Timing ─────────────────────────────────────────────────────
#define DOOR_ALERT_TIMEOUT_MS       0UL  // Red ON immediately when door opens (0 = instant)
#define DOOR_ALERT_ESCALATE_MS   5000UL  // After this long open → start blinking + beeping
#define DOOR_ALERT_BLINK_MS       1000UL  // Red LED blink period (1 Hz)
#define DOOR_ALERT_BEEP_INTERVAL  5000UL  // Double-beep cycle period
#define DOOR_ALERT_BEEP_MS         150UL  // Single beep ON duration
#define DOOR_ALERT_BEEP_GAP_MS     200UL  // Gap between the two beeps in a double-beep

// ─── TMC5160 Config ────────────────────────────────────────────────────────
#define TMC_R_SENSE     0.075f
#define MOTOR_RMS_MA    800       // Motor RMS current in mA

// ─── Motion Constants ──────────────────────────────────────────────────────
// TMC5160 at 256 microsteps = 51200 steps/rev
// Pulley: 20 teeth × 2mm belt pitch = 40mm/rev = 4cm/rev
#define STEPS_PER_REV   51200
#define PULLEY_TEETH    20
#define BELT_PITCH_MM   2
const float STEPS_PER_CM = (float)STEPS_PER_REV / ((PULLEY_TEETH * BELT_PITCH_MM) / 10.0);
// STEPS_PER_CM = 51200 / 4.0 = 12800 steps/cm

const float MAX_DISTANCE_CM = 52.0;

// ─── Ramp Parameters (tuned for 256 microsteps) ────────────────────────────
// At 256 microsteps, internal velocity unit ≈ 0.715 steps/s per count.
// VMAX=500000 ≈ 357,500 steps/s ≈ ~7 rev/s ≈ ~420 RPM — smooth, fast
// HOMING_VMAX is a slow creep to reliably trigger the limit switch
#define VMAX_POSITIONING  500000UL
#define AMAX_VALUE         50000UL
#define DMAX_VALUE         50000UL
#define VSTART_VALUE           10UL
#define VSTOP_VALUE           200UL   // Must be > VSTART; was 10 (too low)
#define VMAX_HOMING         30000UL   // Slow creep for homing

// ─── Presets ──────────────────────────────────────────────────────────────
struct Preset { String name; float cm; };
Preset presets[] = {
  {"HOME", 0.0},
  {"P1",   9.0},
  {"P2",  23.0},
  {"P3",  28.0},
  {"P4",  34.0},
  {"P5",  47.0}
};
const int NUM_PRESETS = 6;

// ─── Global Objects ────────────────────────────────────────────────────────
TMC5160Stepper tmc(PIN_TMC_CS, TMC_R_SENSE);
WebServer server(80);

// ─── Global State ──────────────────────────────────────────────────────────
String currentTargetName = "IDLE";
bool isHomed         = false;
bool triggerHoming   = true;             // Auto-home on boot
uint32_t currentVMAX = VMAX_POSITIONING; // Live speed, updated by /speed endpoint

// ─── Indicator State ───────────────────────────────────────────────────────
unsigned long lastBuzzerToggleMs = 0;    // Tracks last buzzer relay toggle time
bool          buzzerRelayOn      = false; // Current buzzer relay state

// ─── External Indicator Override (set by Python via /indicator) ────────────
// Modes: 0 = auto, 1 = alert (red+buzzer), 2 = green, 3 = off,
//        4 = play_started (green ON immediately), 5 = door_alert (internal)
int  indicatorOverrideMode = 0;
unsigned long overrideBuzzerToggleMs = 0;
bool          overrideBuzzerOn       = false;

// ─── Door Alert State ──────────────────────────────────────────────────────
bool          doorWasOpen         = false;
unsigned long doorOpenSinceMs     = 0;
int           doorAlertPriorMode  = 0;    // mode to restore when door closes
int           doorAlertPhase      = 0;    // 0 = solid red, 1 = blink+beep
unsigned long doorAlertLastBlink  = 0;
bool          doorAlertRedOn      = false;
unsigned long doorAlertLastBeep   = 0;
int           doorAlertBeepCount  = 0;    // 0 = waiting, 1 = first done, 2 = both done
bool          doorAlertBeepOn     = false;
unsigned long doorAlertBeepOnMs   = 0;

// ─── Web Dashboard HTML ────────────────────────────────────────────────────
const char PAGE[] PROGMEM = R"HTML(
<!DOCTYPE html><html><head><meta charset="UTF-8"><meta name="viewport" content="width=device-width,initial-scale=1">
<title>Mouser Rail Controller</title>
<style>
  body{background:#0b0b14;color:#e0e0ff;font-family:sans-serif;display:flex;flex-direction:column;align-items:center;padding:20px}
  .card{background:#16162a;border:1px solid #2a2a4a;border-radius:12px;padding:20px;width:100%;max-width:400px;margin-bottom:15px;box-shadow:0 8px 32px #0006}
  h1{background:linear-gradient(135deg,#f76ae2,#4fc3f7);-webkit-background-clip:text;-webkit-text-fill-color:transparent;font-size:1.5rem}
  .btn-grid{display:grid;grid-template-columns:1fr 1fr;gap:10px}
  button{padding:12px;border:none;border-radius:8px;background:#2a2a4a;color:#fff;font-weight:bold;cursor:pointer;transition:0.2s}
  button:hover{background:#3a3a6a}
  button:disabled{opacity:0.35;cursor:not-allowed}
  .btn-home{background:#3b82f6}
  .btn-bypass{background:#ea580c}
  .btn-stop{background:#ef4444;grid-column:span 2}
  .status{display:flex;justify-content:space-between;font-size:0.9rem;color:#a0a0c0;margin-bottom:10px}
  .val{color:#4fc3f7;font-weight:bold}
  .warn{color:#f59e0b;font-size:0.8rem;text-align:center;margin-top:4px}
  .speed-row{display:flex;align-items:center;gap:10px;margin-top:6px}
  .speed-row label{font-size:0.85rem;color:#a0a0c0;white-space:nowrap}
  .speed-row input[type=range]{flex:1;accent-color:#4fc3f7}
  .speed-val{color:#4fc3f7;font-weight:bold;min-width:44px;text-align:right;font-size:0.9rem}
  .speed-badges{display:flex;gap:6px;margin-top:8px;flex-wrap:wrap}
  .badge{padding:4px 10px;border-radius:6px;background:#2a2a4a;color:#a0a0c0;font-size:0.78rem;cursor:pointer;border:1px solid #3a3a5a}
  .badge:hover{background:#3a3a6a;color:#fff}
</style>
</head><body>
  <h1>🚀 MOUSER RAIL</h1>

  <div class="card">
    <div class="status"><span>Position:</span><span class="val" id="pos">0.0 cm</span></div>
    <div class="status"><span>Status:</span><span class="val" id="stat">IDLE</span></div>
    <div class="status"><span>Homed:</span><span class="val" id="home">NO</span></div>
    <div class="status"><span>Speed:</span><span class="val" id="spd-disp">--</span></div>
  </div>

  <div class="card">
    <div class="status"><span>Speed Control</span></div>
    <div class="speed-row">
      <label>Slow</label>
      <input type="range" id="spd" min="1" max="100" value="50" oninput="updateSpeedLabel()">
      <label>Fast</label>
      <span class="speed-val" id="spd-label">50%</span>
    </div>
    <div class="speed-badges">
      <span class="badge" onclick="setSpeedPct(20)">20% — Slow</span>
      <span class="badge" onclick="setSpeedPct(50)">50% — Normal</span>
      <span class="badge" onclick="setSpeedPct(80)">80% — Fast</span>
      <span class="badge" onclick="setSpeedPct(100)">100% — Max</span>
    </div>
    <button style="width:100%;margin-top:12px" onclick="applySpeed()">Apply Speed</button>
  </div>

  <div class="card btn-grid">
    <button class="btn-home" onclick="cmd('home')">HOME</button>
    <button class="btn-bypass" onclick="cmd('bypass_homing')">BYPASS HOME</button>
    <button onclick="cmd('p1')" id="bp1">P1 (9cm)</button>
    <button onclick="cmd('p2')" id="bp2">P2 (23cm)</button>
    <button onclick="cmd('p3')" id="bp3">P3 (28cm)</button>
    <button onclick="cmd('p4')" id="bp4">P4 (34cm)</button>
    <button onclick="cmd('p5')" id="bp5">P5 (47cm)</button>
    <button class="btn-stop" onclick="cmd('stop')">🛑 STOP RAIL</button>
  </div>
  <p class="warn" id="warn"></p>

<script>
  // VMAX range: 50000 (min) to 500000 (max) — maps to slider 1–100%
  const VMAX_MIN = 50000, VMAX_MAX = 500000;

  function pctToVmax(pct){ return Math.round(VMAX_MIN + (VMAX_MAX - VMAX_MIN) * pct / 100); }
  function vmaxToPct(v)  { return Math.round((v - VMAX_MIN) / (VMAX_MAX - VMAX_MIN) * 100); }

  function updateSpeedLabel(){
    document.getElementById('spd-label').innerText = document.getElementById('spd').value + '%';
  }
  function setSpeedPct(pct){
    document.getElementById('spd').value = pct;
    updateSpeedLabel();
  }
  function applySpeed(){
    const pct  = parseInt(document.getElementById('spd').value);
    const vmax = pctToVmax(pct);
    fetch('/speed?v=' + vmax);
  }
  function cmd(c){ fetch('/'+c); }

  setInterval(async ()=>{
    try{
      const r = await fetch('/status');
      const d = await r.json();
      document.getElementById('pos').innerText  = d.absCm.toFixed(1) + ' cm';
      document.getElementById('stat').innerText = d.running ? 'MOVING...' : d.point;
      document.getElementById('home').innerText = d.homed ? 'YES' : (d.homing ? 'HOMING...' : 'NO');
      document.getElementById('spd-disp').innerText = vmaxToPct(d.vmax) + '% (' + d.vmax + ')';
      ['bp1','bp2','bp3','bp4','bp5'].forEach(id=>{
        document.getElementById(id).disabled = !d.homed;
      });
      document.getElementById('warn').innerText = d.homed ? '' : 'Preset moves locked until homed.';
    }catch(e){}
  }, 400);
</script>
</body></html>
)HTML";

// ─── Motor Control ─────────────────────────────────────────────────────────
void moveToIndex(int index) {
  // FIX 6: Guard — do not move to preset before homing
  if (!isHomed) {
    Serial.println("[WARN] Preset move requested before homing — ignored.");
    return;
  }
  if (index < 0 || index >= NUM_PRESETS) return;

  float targetCm    = presets[index].cm;
  int32_t targetPos = (int32_t)(targetCm * STEPS_PER_CM);

  // Clamp to physical travel limits
  int32_t maxSteps = (int32_t)(MAX_DISTANCE_CM * STEPS_PER_CM);
  targetPos = constrain(targetPos, 0, maxSteps);

  currentTargetName = presets[index].name;
  tmc.RAMPMODE(0);          // Positioning mode
  tmc.VMAX(currentVMAX);   // Use live speed setting
  tmc.XTARGET(targetPos);

  Serial.printf("[MOVE] → %s (%.1f cm = %d steps)\n",
                presets[index].name.c_str(), targetCm, targetPos);
}

void stopMotor() {
  // Stop by setting XTARGET = current position
  tmc.XTARGET(tmc.XACTUAL());
  currentTargetName = "STOPPED";
  Serial.println("[STOP] Motor halted.");
}

float readTemperatureC() {
  long sum = 0;
  for (int i = 0; i < NTC_SAMPLES; i++) {
    sum += analogRead(PIN_NTC_TEMP);
    delayMicroseconds(200);  // Brief gap between samples
  }
  int raw = (int)(sum / NTC_SAMPLES);

  if (raw <= 0 || raw >= 4095) {
    return -99.0f;  // Open circuit or shorted
  }

  // NTC to GND, pull-up (10k) to 3.3V
  // R_ntc = R_pullup * raw / (4095 - raw)
  float resistance = NTC_PULLUP * (4095.0f - (float)raw) / (float)raw;

  // Steinhart-Hart B-parameter equation
  float tempK = 1.0f / (1.0f / TEMP_NOMINAL + logf(resistance / NTC_NOMINAL) / NTC_BETA);
  return tempK - 273.15f;
}

bool isDoorClosed() {
  return digitalRead(PIN_DOOR_SENSOR) == LOW;  // 54140: LOW = magnet present = door closed
}

// ─── Status Handler ────────────────────────────────────────────────────────
void handleStatus() {
  int32_t currentSteps = tmc.XACTUAL();
  bool isMoving = (tmc.XACTUAL() != tmc.XTARGET());
  String json = "{";
  json += "\"running\":"  + String(isMoving      ? "true" : "false");
  json += ",\"homed\":"   + String(isHomed        ? "true" : "false");
  json += ",\"homing\":"  + String(triggerHoming  ? "true" : "false");
  json += ",\"point\":\"" + currentTargetName + "\"";
  json += ",\"absCm\":"   + String((float)currentSteps / STEPS_PER_CM, 2);
  json += ",\"steps\":"   + String(currentSteps);
  json += ",\"vmax\":"    + String(currentVMAX);
  json += ",\"tempC\":"   + String(readTemperatureC(), 1);
  json += ",\"doorOpen\":" + String(isDoorClosed() ? "false" : "true");
  json += "}";
  server.sendHeader("Access-Control-Allow-Origin", "*");
  server.send(200, "application/json", json);
}

// ─── TMC5160 Initialization ────────────────────────────────────────────────
void initTMC() {
  // FIX 1: CS HIGH before any SPI activity to prevent garbage init
  pinMode(PIN_TMC_CS, OUTPUT);
  digitalWrite(PIN_TMC_CS, HIGH);

  // Disable driver during config
  pinMode(PIN_TMC_EN, OUTPUT);
  digitalWrite(PIN_TMC_EN, HIGH);

  delay(20);  // Let power rails settle

  SPI.begin(PIN_TMC_SCK, PIN_TMC_MISO, PIN_TMC_MOSI);
  tmc.begin();

  // Basic driver config
  tmc.toff(4);
  tmc.rms_current(MOTOR_RMS_MA);
  tmc.microsteps(256);

  // shaft(false): positive XTARGET = motor moves in its natural forward direction.
  // Homing now uses a large negative XTARGET (positioning mode) so this setting
  // no longer affects homing direction at all — only preset moves P1..P5.
  // If presets move LEFT instead of RIGHT after homing, flip this to shaft(true).
  tmc.shaft(true);

  // FIX 2: Ramp parameters scaled for 256 microsteps
  tmc.RAMPMODE(0);                   // Positioning mode
  tmc.VSTART(VSTART_VALUE);
  tmc.VSTOP(VSTOP_VALUE);            // FIX 3: Was 10 — too low, causes faults
  tmc.VMAX(VMAX_POSITIONING);
  tmc.AMAX(AMAX_VALUE);
  tmc.DMAX(DMAX_VALUE);

  // A1/D1/V1 for two-phase ramp (optional but smoother)
  tmc.v1(VMAX_POSITIONING / 2);
  tmc.a1(AMAX_VALUE * 2);
  tmc.d1(DMAX_VALUE * 2);

  // Enable driver
  digitalWrite(PIN_TMC_EN, LOW);

  Serial.println("[TMC] Driver initialised OK.");
  Serial.printf("[TMC] STEPS_PER_CM = %.1f\n", STEPS_PER_CM);
}

// ─── Homing Sequence (non-blocking) ───────────────────────────────────────
void runHomingSequence() {
  static bool homingStarted = false;

  if (!homingStarted) {
    // Stop any in-progress move first
    if (tmc.XACTUAL() != tmc.XTARGET()) {
      tmc.XTARGET(tmc.XACTUAL());
      delay(50);
    }

    Serial.println("[HOME] Sequence started — seeking switch...");

    // Use VELOCITY mode (RAMPMODE 2) to move negative toward the switch
    // matches the logic in stepper_control_v2.ino
    tmc.RAMPMODE(2);
    tmc.VMAX(VMAX_HOMING);

    homingStarted = true;
    currentTargetName = "HOMING";
  }

  // Check home switch (active LOW)
  if (digitalRead(PIN_BUTTON_S2) == LOW) {
    // Switch triggered — immediately stop and switch back to positioning mode
    tmc.RAMPMODE(0);
    tmc.VMAX(0);
    delay(50);
    tmc.XACTUAL(0);                       // Zero the position register
    tmc.XTARGET(0);
    tmc.VMAX(currentVMAX);               // Restore user speed for presets

    isHomed        = true;
    triggerHoming  = false;
    homingStarted  = false;
    currentTargetName = "HOME";

    Serial.println("[HOME] Success! Position zeroed.");
    Serial.printf("[HOME] STEPS_PER_CM=%.1f  max travel=%d steps\n",
                  STEPS_PER_CM, (int32_t)(MAX_DISTANCE_CM * STEPS_PER_CM));
  }
}

// ─── Speed Handler ─────────────────────────────────────────────────────────
void handleSpeed() {
  if (!server.hasArg("v")) {
    server.send(400, "text/plain", "Missing ?v= parameter");
    return;
  }
  uint32_t requested = (uint32_t)server.arg("v").toInt();
  // Clamp to safe range
  requested = constrain(requested, 50000UL, VMAX_POSITIONING);
  currentVMAX = requested;

  // Apply immediately if not homing
  if (!triggerHoming) {
    tmc.VMAX(currentVMAX);
  }

  Serial.printf("[SPEED] VMAX set to %u\n", currentVMAX);
  server.send(200, "text/plain", "OK");
}
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
void loop() {
  server.handleClient();

  // Run homing state machine if triggered
  if (triggerHoming) {
    runHomingSequence();
  }

  // Emergency stop ONLY if home switch triggered while moving TOWARDS home
  if (!triggerHoming && isHomed) {
    if (digitalRead(PIN_BUTTON_S2) == LOW && tmc.XTARGET() < tmc.XACTUAL()) {
      Serial.println("[SAFETY] Home switch triggered while moving negative — stopping.");
      stopMotor();
    }
  }

  // Monitor door sensor; escalate to alert if open too long
  updateDoorAlert();

  // Update 12V relay indicators every loop cycle (non-blocking)
  updateIndicators();

  yield();
}

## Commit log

2026-07-18 Initial import: MechArm vision dashboard
    Add complete project scaffold for MechArm 270 vision-driven assembly dashboard. Includes core Python app entry (main.py), configuration (config.py), README and MIT LICENSE, Flask templates and static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
    [Belt Retainer.stl, Belt Tensioner.stl, Idler_Pulley_Base.stl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]
2026-07-18 Create linear rail gif.gif
2026-07-21 Add GIF images for PCB, robotic arm, control panel
